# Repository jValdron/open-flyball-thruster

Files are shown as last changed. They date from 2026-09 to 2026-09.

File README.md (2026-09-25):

# open-flyball-thruster (OFT)

## Contents
- [Introduction](#introduction)
- [Flyball?](#flyball)
- [Word of Warning](#word-of-warning)
- [Instructions](#instructions)
  - [Assembly Timelapse](#assembly-timelapse)
- [Design](#design)
- [Contributions](#contributions)
- [License](#license)

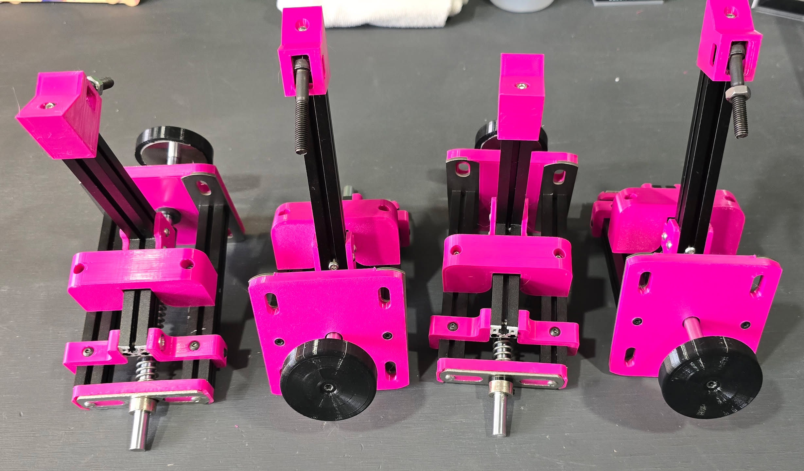
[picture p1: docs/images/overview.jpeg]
Overview of 4 thrusters


## Introduction
An **open-source**, **low-cost** [flyball](https://en.wikipedia.org/wiki/Flyball) thruster design aimed at DIY builders. This repository covers the **thrusters only**; it does not include any instructions for building a flyball box.

Thrusters are built from a mix of **printed parts** and **off-the-shelf hardware**, with some basic machining required. Printed parts are defined in [OpenSCAD](https://openscad.org/), with some customization available.

The target cost is, currently, approximately **$35 USD** per thruster, excluding tools and printer access.

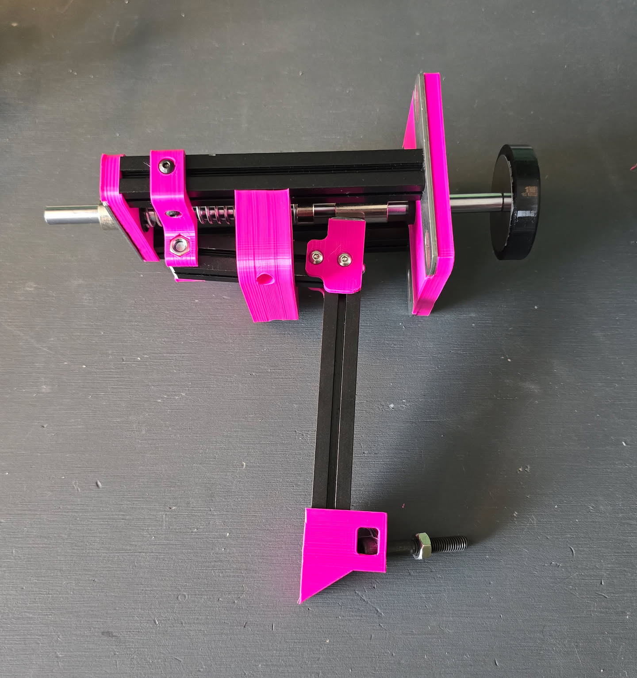
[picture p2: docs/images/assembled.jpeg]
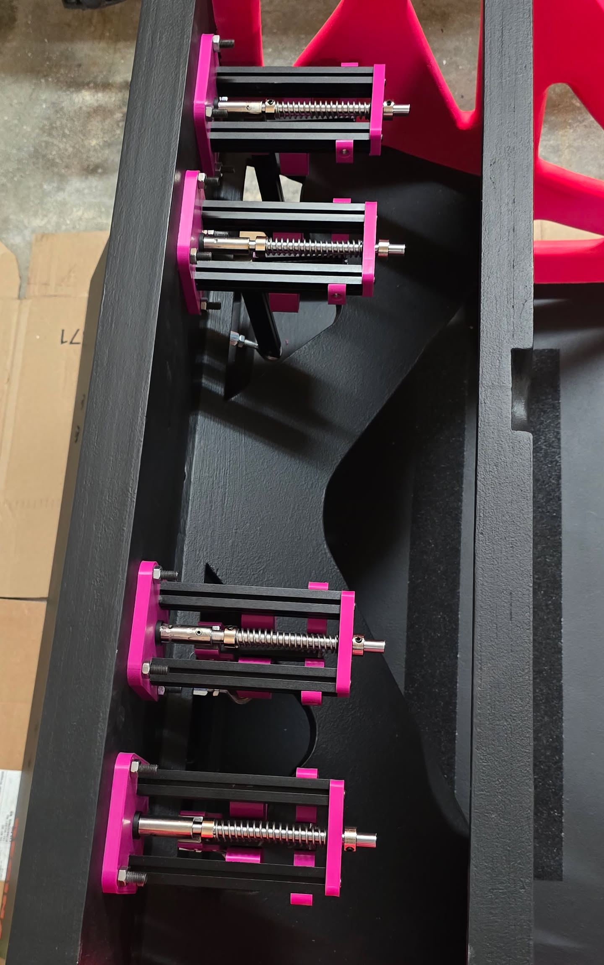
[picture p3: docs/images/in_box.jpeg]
Mounted in a box
|  |  |
|:---:|:---:|
| Side view | 4 thrusters mounted in a box (first version, no baffles/pedal connector) |

## Flyball?
If you don't know flyball, you probably don't need a flyball box thruster. Flyball is a fast paced team dog sport. It's somewhat of a relay race where four dogs race over jumps, trigger a box to retrieve a ball (shot out by a thruster) and race back while then next dog goes.

Common organizations are [NAFA](https://www.nafaflyball.com/) and [U-FLI](https://u-fli.com/) in North America, [BFA](https://www.flyball.org.uk/) and [UKFL](https://www.ukflyball.org.uk/) in the UK, and there are more in other parts of the world.

## Word of Warning
If you're here, you're most likely looking at building your own thruster. My first word of warning is that you probably shouldn't. You're better off buying thrusters from established suppliers, for example:
  - **[Jarvis Flyball Box](https://www.flyballbox.ca/)** (Canada)
  - **[Sub 15](https://www.facebook.com/p/Sub-15-61551941167602/)** (UK)
  
<sub>Please let me know if you would like your name added to or removed from the list above.</sub>

The OFTs:
- **are not battle-tested.** As of this writing, they haven't been used for more than a year. We've used them weekly at practice and a half dozen of times at various tournaments. They've been working without much issues for us and the last iteration has been pretty solid.

- **has many small parts.** Since these combine 3D printed parts and metal parts instead of custom machined parts, they contain many more small parts than a machined thruster would, making them more susceptible to breaking.

- **has 3D printed parts.** Some tension/stress will happen on printed parts, so you should fully expect some parts to break at some point. However, this was engineered in a way where most of the tension and stress will be distributed on metal fasteners and baffles. The important bits are mostly all metal. The printed parts are mostly there to support fasteners or metal parts.

- **should have spare parts.** I would definitely recommend you keep spare parts on hand, and ideally a complete spare thruster, so you can quickly replace failed components.

- **has no support or warranty.** All of the files and instructions provided in this repository are provided as is and with no support or warranty. I am not responsible for any accident, injuries or whatever happens while building or using these.

- **was built with AI-assisted SCAD.** The original design was completely done in Fusion 360, but at some point I stopped using Fusion and switched to OpenSCAD. [Cursor](https://cursor.com/) was used to help re-write the parts in OpenSCAD; they may contain errors, need iteration or might be sub-optimal.

## Instructions
This project is for **DIY-ers only**. You should have:

- **Basic metal-cutting tools** (e.g. saw, drill, tap and dies, etc) to machine some of the metal parts.
- **Access to a 3D printer** (your own or a maker space) for printing the OpenSCAD-generated parts.

Familiarity with OpenSCAD is helpful if you want to tweak dimensions or part geometry.

Acquire [parts (bom.md)](docs/bom.md) and follow [instructions.md](docs/instructions.md) to get started.

TL;DR:
* Obtain the all parts, see [docs/bom.md](docs/bom.md)
* Get the parts prepared, see [docs/instructions.md](docs/instructions.md)
* Assemble the thruster, see [docs/assembly.md](docs/assembly.md)
* Tune as necessary, see [docs/tuning.md](docs/tuning.md)

### Assembly Timelapse
https://github.com/user-attachments/assets/54a8cb0c-5971-4721-8ede-dae078966e4b

## Design

This is a fairly standard flyball thruster. A **main spring** on a **linear rod** drives the ball; a **shaft coupler** gives the rod two positions (rest and loaded). A **hammer/striker** holds the rod in the secondary (loaded) position via a small spring.

**To load:** Push back on the **plunger**. The thruster stays in the loaded position. The hammer head bears against the rod and keeps it in the secondary position.

**To fire:** Something must push back or down on the hammer to release the rod, typically a **bolt** between the box’s pedal and the hammer. The optional **pedal connector** is a printed part that sits between the pedal and the hammer to carry that screw.

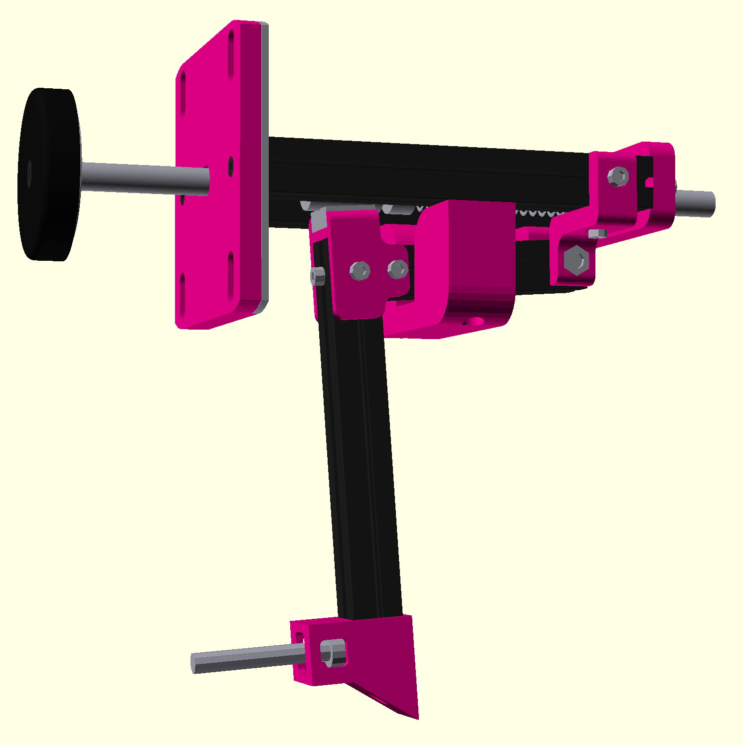
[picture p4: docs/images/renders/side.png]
Side view
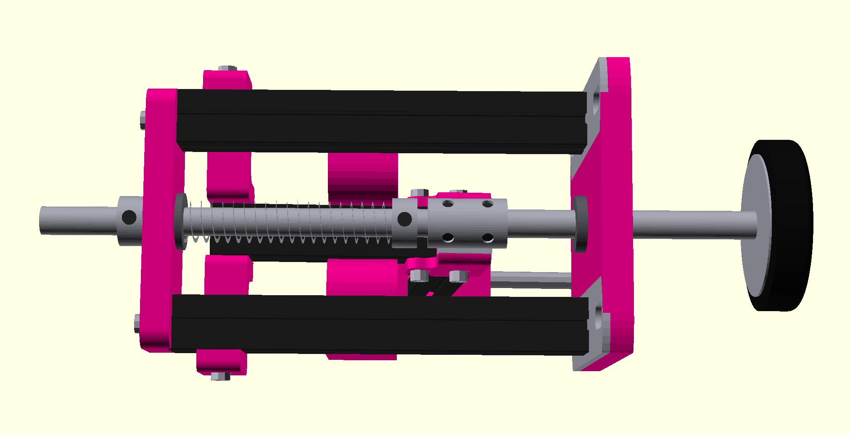
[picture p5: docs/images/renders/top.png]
Top view
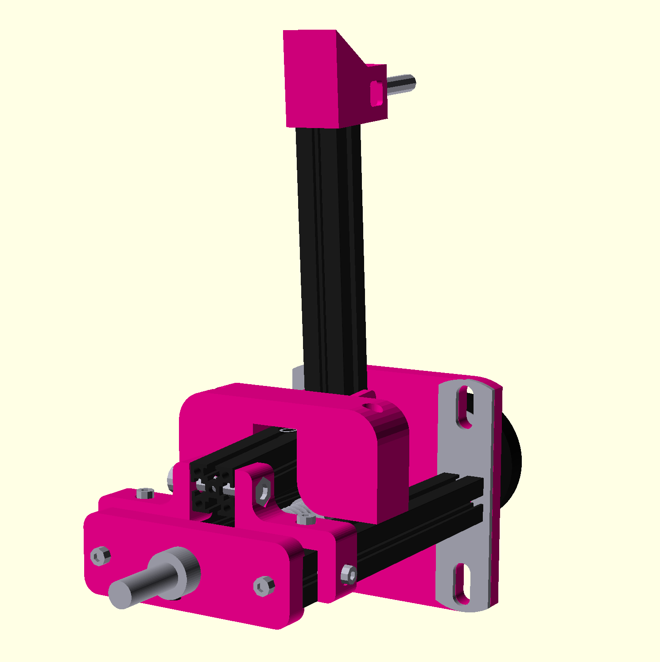
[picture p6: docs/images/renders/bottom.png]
Bottom view
|  |  |  |
|:---:|:---:|:---:|
| Side view | Top view | Bottom view |

## Contributions
Feel free to submit a pull request or start a discussion if you want to discuss something, but again, I do not provide support for these.

## License
All files are licensed as CC BY-NC-SA 4.0.

See [LICENSE](LICENSE) for the full legal text.

These designs are free to use, modify, and manufacture for personal and non-commercial club use. Commercial manufacture, sale, or commercial distribution is not permitted without permission from the author.

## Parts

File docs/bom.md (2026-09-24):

# Bill of Materials (BOM)

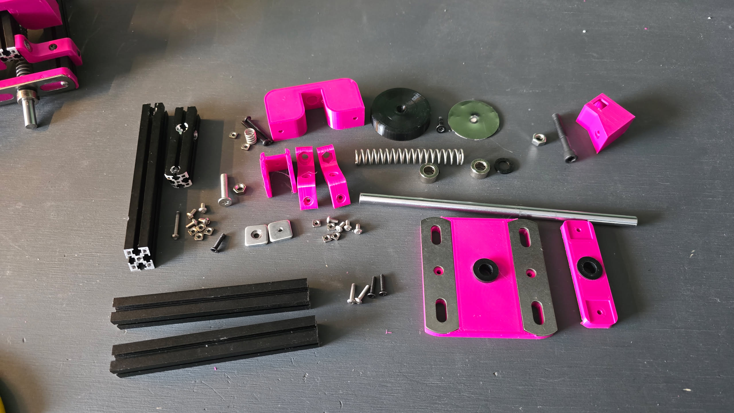
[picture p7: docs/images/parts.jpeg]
All parts (not 100% accurate)


## Intended configuration

This list is sized for a thruster mounted on a faceplate made of a double stack of 3/4" plywood (1½" total) with thinner matting (~¼") on top. As built, the thruster is quite adjustable, so small differences in board or matting thickness can usually be taken up without changing parts.

If the box is much different from that stack, you will likely need to tweak a few dimensions. The ones that matter most are the linear rod, the main spring, and potentially the extrusion lengths.

## BOM

Per-thruster parts list. Multiply quantities by the number of thrusters you want to build.

Prices are approximate (CAD from original sources); expect ~\$45–50 CAD, or ~\$35 USD, per thruster depending on source and shipping.

Some parts are best bought in bulk, such as the aluminum extrusion and any fasteners.

| Qty | Item | Cost/unit | Total | Notes / link |
|-----|---|---|---|---|
| | [Printed Parts – PETG](https://www.overture3d.ca/products/basic-petg-1-75mm-1-pack) | ~$2.49 | ~$2.49 | Print from STLs in `models/` |
| | [Printed Parts – TPU](https://www.overture3d.ca/products/tpu-1-75mm-1-pack) | ~$0.65 | ~$0.65 | |
| 2 | [1515 aluminum profiles × 115 mm](https://www.amazon.ca/dp/B06XJ42W51) (profile) | $3.34 [^1] | $6.68 | 15×15 mm extrusion for main profile |
| 1 | 1515 aluminum profiles × 65 mm (hammer) | $1.87 [^1] | $1.87 | Hammer top extrusion  |
| 1 | 1515 aluminum profiles × 135 mm (hammer) | $3.88 [^1] | $3.88 | Hammer side extrusion |
| 2 | [80×20×2 mm 304 stainless steel baffle](https://www.aliexpress.com/item/1005010628242895.html) | $3.92 | $7.84 | For the base. Optional, could be done without, but highly recommended due to strength it provides. Substitute listing — these are not the baffles originally used; that item is no longer listed |
| 1 | [70×20×2 mm 304 stainless steel baffle](https://www.aliexpress.com/item/1005010628242895.html) | $4.00 | $4.00 | For the backstop. Optional, also could be done without, but highly recommended due to strength |
| 1 | [M4x15x15x3mm square nut](https://www.aliexpress.com/item/1005008724571592.html?spm=a2g0o.order_list.order_list_main.181.52d11802MeMOAG) | $0.25 | $0.25 | Technically optional, can be printed instead but highly recommended that you machine it |
| 1 | [8 mm OD × 200 mm linear shaft with M4 threaded holes](https://www.aliexpress.com/item/1005007982728863.html) | $9.54 | $9.54 | ~7" |
| 1 | [12 mm OD × 1.2 mm wire × 70 mm compression spring](https://www.aliexpress.com/item/1005005402569008.html) | $0.93 | $0.93 | Main spring |
| 1 | [8 mm OD × 0.9 mm wire × 10 mm compression spring](https://www.aliexpress.com/item/1005005402584700.html) | $0.33 | $0.33 | Hammer spring |
| 2 | [8 mm shaft lock collar (T8)](https://www.aliexpress.com/item/32830905214.html) | $0.52 | $1.05 | |
| 1 | [40×40 mm metal plate disk](https://www.aliexpress.com/item/1005008983416584.html) | $0.56 | $0.56 | |
| 1 | [8–8 mm shaft coupler](https://www.aliexpress.com/item/1005010151471423.html) | $1.64 | $1.64 | |
| 4 | [M4 × 3 mm grub screws](https://www.aliexpress.com/item/1005007184737120.html) | $0.14 | $0.55 | |
| 2 | [M8 T-shaped nylon washer/bushing](https://www.aliexpress.com/item/1005008152448252.html) | $0.20 | $0.40 | |
| 1 | [M4 × 14 mm countersunk Torx machine screws](https://www.aliexpress.com/item/4001255830388.html) | $0.12 | $0.12 | |
| 3 | [M3 × 14 mm countersunk Torx machine screws](https://www.aliexpress.com/item/4001255830388.html) | $0.08 | $0.24 | |
| 8 | [M3 × 6 mm button head machine screws](https://www.aliexpress.com/item/32967225441.html) | $0.05 | $0.43 | |
| 2 | [M3 × 10 mm button head machine screws](https://www.aliexpress.com/item/32967225441.html) | $0.06 | $0.13 | |
| 2 | [M3 × 12 mm button head machine screws](https://www.aliexpress.com/item/32967225441.html) | $0.07 | $0.13 | |
| 1 | [M3 × 25 mm socket head cap machine screws](https://www.aliexpress.com/item/32980100109.html) | $0.10 | $0.10 | |
| 2 | [M3 × 30 mm button head machine screws](https://www.aliexpress.com/item/32967225441.html) | $0.10 | $0.20 | |
| 10 | [M3 square nuts](https://www.aliexpress.com/item/1005009866787243.html) | $0.05 | $0.50 | To fasten parts on the 15x15 extrusion |
| 1 | [M5 × 25 mm flat Torx machine screws](https://www.aliexpress.com/item/1005002254557923.html) | $0.87 | $0.87 | Hammer/catcher pivot |
| 1 | [M5 nuts](https://www.aliexpress.com/item/1005007593861199.html) | $0.12 | $0.12 | Hammer/catcher pivot |
| 4 | [M6 × 60 mm machine screws](https://www.aliexpress.com/item/1005008846077891.html) | $0.59 | $2.38 | Used to mount to the box, longer/shorter screws might be needed depending on faceplate thickness |
| 4 | [M6 nuts](https://www.aliexpress.com/item/1005007593861199.html) | $0.15 | $0.60 | Used to mount to the box |
| 1 | [M6 × 10 mm × 40 mm hex rod coupling nuts](https://www.aliexpress.com/item/1005006565508071.html) | $1.02 | $1.02 | Optional, pedal connector |
| 1 | [M6 × 40 mm partially threaded machine screws](https://www.aliexpress.com/item/32860422627.html) | $0.81 | $0.81 | Optional, pedal connector |
| 1 | [M6 × 20 mm flat head machine screws](https://www.aliexpress.com/item/1005008614137094.html) | $0.56 | $0.56 | Optional, pedal connector |
| | | | **~\$48.48** | Main list total (CAD) |
| | | | **+\$2.39** | With optional pedal connector (CAD) |

[^1]: **Aluminum extrusion unit cost:** Extrusion is bought in bulk (e.g. a pack of 4 × 1000 mm). The cost/unit shown is the **price per mm** (total pack price ÷ 4000 mm) × the length of that profile.

##  Notes

- **Printed parts:** Print all STLs in `models/` from the PETG and TPU allocations above (see [instructions.md](instructions.md) for print settings).
- **1515 profiles:** Often sold in multi-packs; one pack may cover several thrusters.
- **Sourcing:** Links are from the original BOM (Overture, Amazon.ca, AliExpress). You can substitute equivalent parts from local or preferred suppliers; confirm dimensions and thread specs (M3/M4/M5/M6) match.
- **Currency:** Original prices in CAD. USD equivalent is roughly 25–30% less depending on exchange rate.

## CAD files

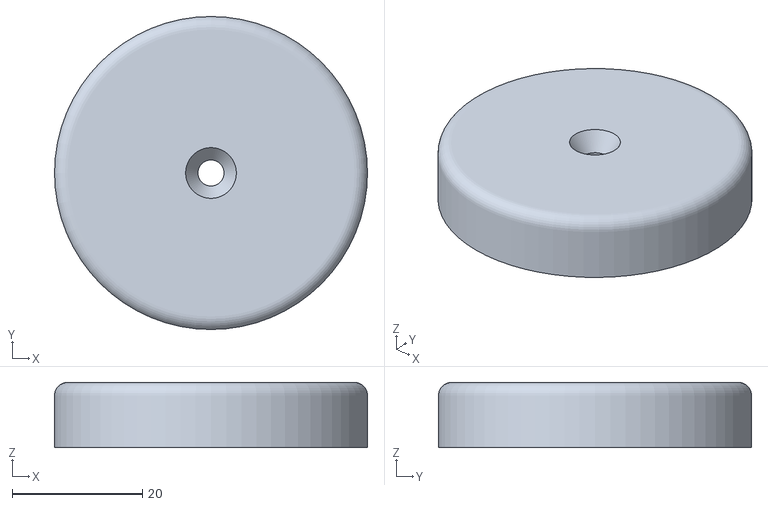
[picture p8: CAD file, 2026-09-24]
models/plunger.stl
48.0 x 48.0 x 10.0

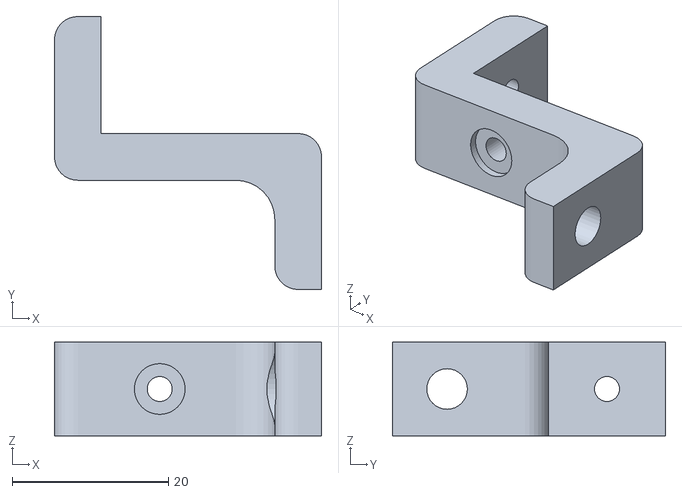
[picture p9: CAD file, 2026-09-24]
models/hammer_holder.stl
34.2 x 35.0 x 12.0

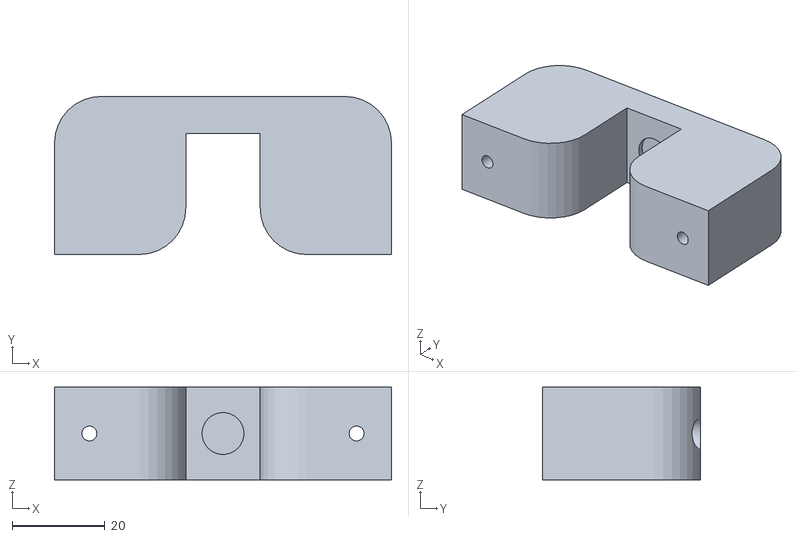
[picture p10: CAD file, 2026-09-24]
models/spring_holder.stl
72.5 x 34.0 x 20.0

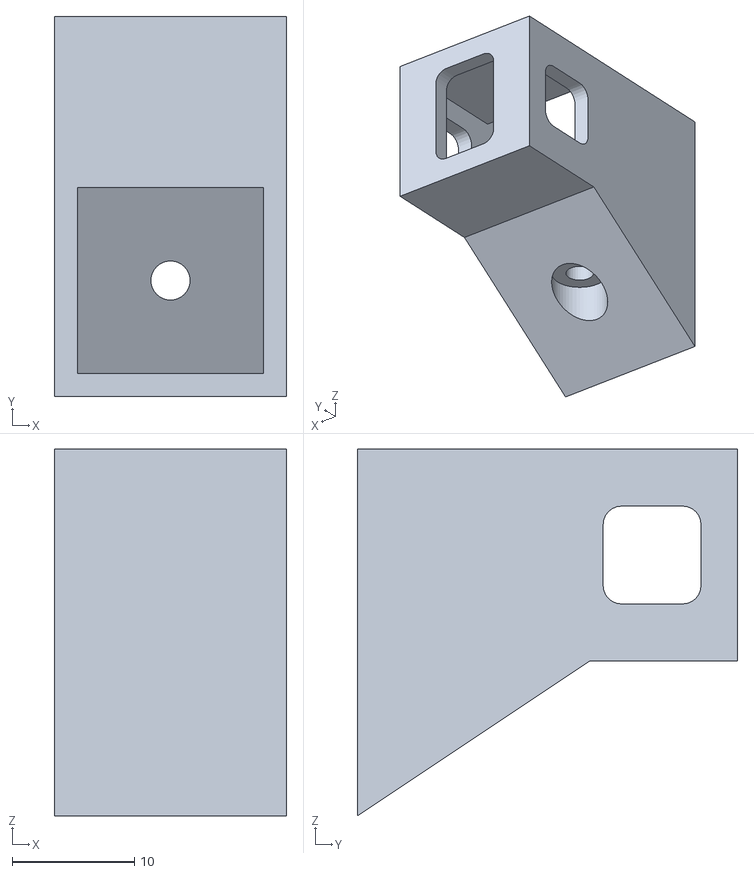
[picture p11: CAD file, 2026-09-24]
models/pedal_connector.stl
19.0 x 31.1 x 30.0

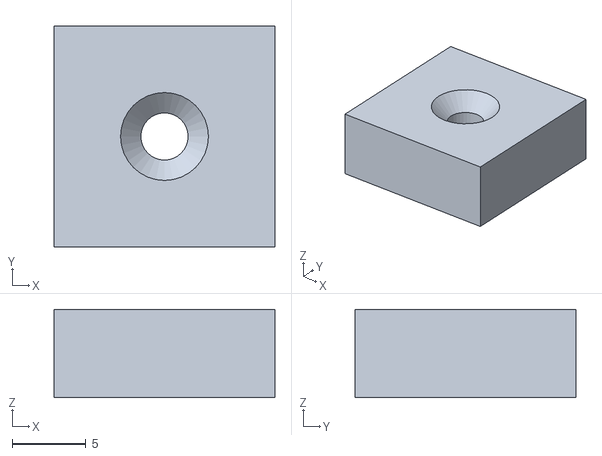
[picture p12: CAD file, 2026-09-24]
models/hammer_head.stl
15.0 x 15.0 x 6.00

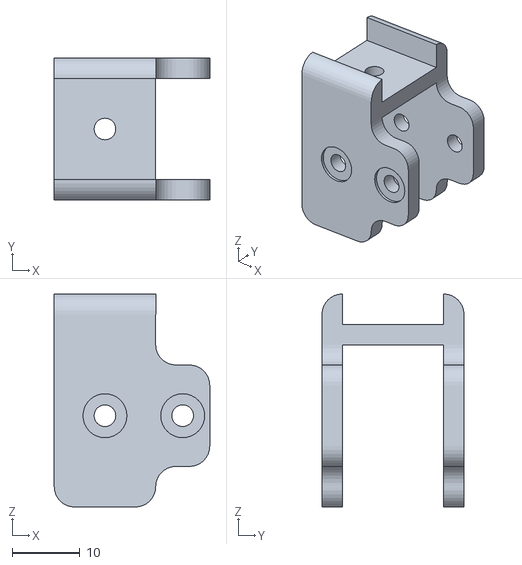
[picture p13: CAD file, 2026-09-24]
models/hammer_joint.stl
23.0 x 21.0 x 31.5

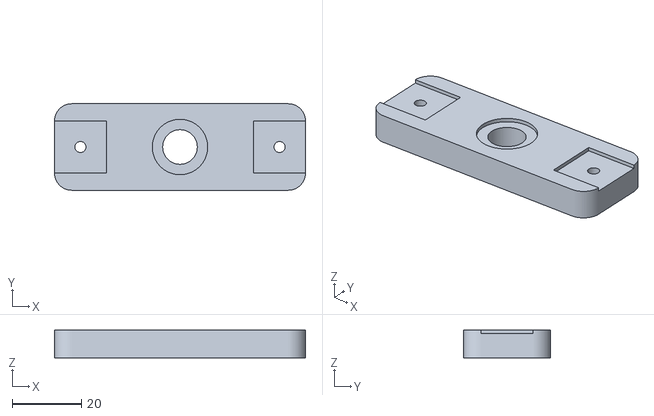
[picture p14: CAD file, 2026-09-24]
models/backstop.stl
72.5 x 25.0 x 8.00

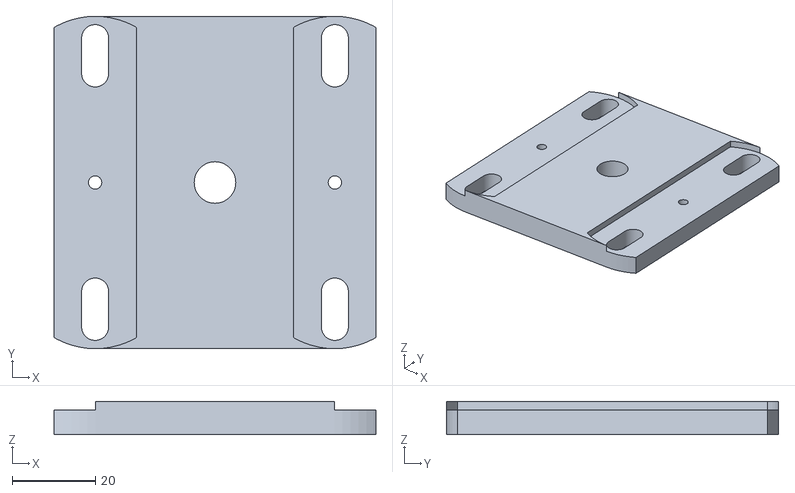
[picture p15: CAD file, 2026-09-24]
models/base.stl
77.5 x 80.0 x 8.00

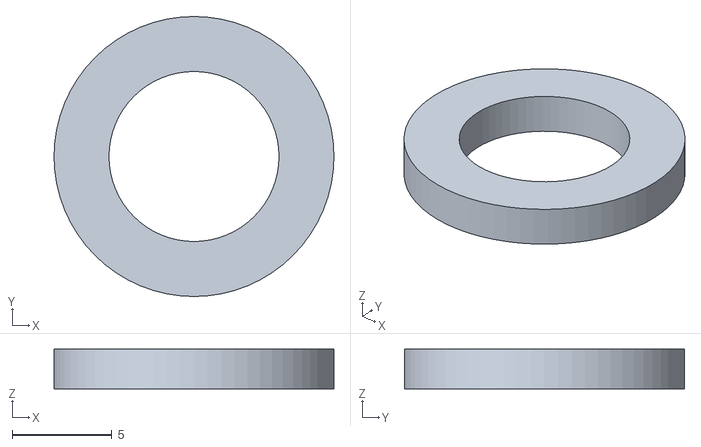
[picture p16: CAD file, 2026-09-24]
models/washer.stl
14.0 x 14.0 x 2.00

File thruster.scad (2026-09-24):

use <scad/lib/makerbeam.scad>
use <scad/lib/baffle.scad>
use <scad/lib/collars.scad>
use <scad/lib/t_bushing.scad>
use <scad/lib/compression_spring.scad>

use <BOLTS.scad>

use <scad/base.scad>
use <scad/backstop.scad>
use <scad/plunger.scad>
use <scad/hammer_holder.scad>
use <scad/hammer_joint.scad>
use <scad/hammer_head.scad>
use <scad/spring_holder.scad>
use <scad/pedal_connector.scad>

petg_color = [0.929, 0.0, 0.549];
extrusion_color = [0.12, 0.12, 0.12];
steel_color = [0.65, 0.65, 0.7];
anodized_steel_color = [0.15, 0.15, 0.15];
tpu_color = [0.05, 0.05, 0.05];
nylon_color = [0.35, 0.35, 0.38];

plate_size = [77.5, 80];
baffle_width = 19.9;
baffle_x_offset = plate_size[0]/2 - baffle_width/2;
plate_thickness = 8;
baffle_thickness = 2;

extrusion_length = 115;
hammer_top_extrusion_length = 65;
extrusion_groove_depth = 1;
extrusion_size = 15;

extrusion_center_offset = plate_size[0] / 2 - baffle_width / 2;
distance_between_outside_faces_of_extrusions = 2 * extrusion_center_offset + extrusion_size;

main_spring_od = 12;
main_spring_wire_d = 1.2;
main_spring_length = 70;

hammer_spring_od = 8;
hammer_spring_wire_d = 0.9;
hammer_spring_length = 10;

hammer_holder_depth = 12;
hammer_holder_backstop_offset = 8;
hammer_holder_wall = 6;
hammer_holder_x_offset = extrusion_size / 2 + hammer_holder_wall;
hardware_holder_height = 14;
hammer_holder_total_height = extrusion_size + hammer_holder_wall + hardware_holder_height;
hammer_holder_clearance_below_center = 10;
hammer_holder_z_offset = hammer_holder_total_height / 2 + hammer_holder_clearance_below_center;
hammer_holder_m3_groove_depth = 1;
hammer_holder_inner_corner_radius = 5;
hammer_extrusion_play = 1;
hammer_holder_extra_width = extrusion_center_offset - extrusion_size - hammer_holder_wall - hammer_extrusion_play / 2;
hammer_top_extrusion_offset = 3;
hammer_top_extrusion_m5_through_hole_d = 6.5;
hammer_top_extrusion_spring_holder_hole_d = 9;
hammer_top_extrusion_spring_holder_hole_offset = 20;
hammer_side_extrusion_length = 135;
hammer_side_extrusion_short_length = 125;
pedal_connector_z_offset = 15;
pedal_connector_m6_bolt_length = 40;

spring_holder_y_offset = 52.5;
spring_holder_height = 31;
spring_holder_thickness = 20;
spring_holder_screw_length = 30;
spring_holder_screw_extra_for_nut = 7;
spring_holder_m3_groove_depth = max(0, -1 * (spring_holder_height - spring_holder_screw_length - spring_holder_screw_extra_for_nut));

hammer_joint_wall = 3;
hammer_joint_bottom_offset = 6;
hammer_joint_right_offset = 8;
hammer_head_height_offset = 4.5;
hammer_head_height = 6;

linear_shaft_length = 200;
linear_shaft_extension = 40;
m4_tap_depth = 15;

plunger_disc_thickness = 0.6;
plunger_disc_radius = 20;
plunger_thickness = 10;
m4_screw_length = 16;

// Base plate
color(petg_color) {
    rotate([-90, 0, 0]) {
        base();
    }
}

// T-bushing in base plate
t_bushing_flange_thickness = 3;
color(nylon_color) {
    translate([0, plate_thickness + t_bushing_flange_thickness, 0]) {
        rotate([90, 0, 0]) {
            t_bushing();
        }
    }
}

// Linear shaft
color(steel_color) {
    translate([0, -linear_shaft_extension, 0]) {
        rotate([-90, 0, 0]) {
            difference() {
                // Rod
                cylinder(h = linear_shaft_length, r = 4, $fn = 64);

                // Tapped M4 hole
                translate([0, 0, -0.5]) {
                    cylinder(h = m4_tap_depth + 1, r = 1.65, $fn = 64);
                }
            }

            // Plunger Disc
            difference() {
                cylinder(h = plunger_disc_thickness, r = plunger_disc_radius, $fn = 64);
                translate([0, 0, -0.5]) {
                    cylinder(h = 1.6, r = 2.5, $fn = 64);
                }
            }
        }
    }
}

// Plunger
color(tpu_color) {
    translate([0, -linear_shaft_extension, 0]) {
        rotate([-90, 0, 0]) {
            rotate([0, 180, 0]) {
                translate([0, 0, plunger_disc_thickness]) {
                    plunger();
                }
            }
        }
    }
}

// M4 countersunk hex socket screw
// Goes through plunger and disc into tapped hole
color(anodized_steel_color) {
    translate([0, -linear_shaft_extension, 0]) {
        rotate([-90, 0, 0]) {
            rotate([0, 180, 0]) {
                translate([0, 0, plunger_disc_thickness + plunger_thickness]) {
                    rotate([180, 0, 0]) {
                        MetricHexSocketCountersunkHeadScrew(key="M4", l=m4_screw_length);
                    }
                }
            }
        }
    }
}

// Backstop
backstop_thickness = 8;
linear_shaft_groove_depth = 2;
backstop_y = extrusion_length + plate_thickness * 2 - extrusion_groove_depth;
stop_collar_thickness = 7;
stop_collar_od = 14;
spring_stop_collar_y = 55;
shaft_coupling_y = 30;

color(petg_color) {
    rotate([90, 0, 0]) {
        translate([0, 0, -extrusion_length - plate_thickness*2 + extrusion_groove_depth]) {
                backstop();
        }
    }
}

// T-bushing in backstop groove
color(nylon_color) {
    t_bushing_flange_thickness = 3;
    t_bushing_body_height = 5;
    bushing_length = t_bushing_flange_thickness + t_bushing_body_height;
    translate([0, backstop_y - backstop_thickness - linear_shaft_groove_depth, 0]) {
        rotate([-90, 0, 0]) {
            t_bushing();
        }
    }
}

// Main compression spring
backstop_bushing_front_y = backstop_y - backstop_thickness - linear_shaft_groove_depth + bushing_length;
spring_collar_face_y = spring_stop_collar_y + stop_collar_thickness / 2;
spring_length = backstop_bushing_front_y - spring_collar_face_y;

color(steel_color) {
    translate([0, spring_collar_face_y, 0]) {
        rotate([-90, 0, 0]) {
            compression_spring(
                od = main_spring_od,
                wire_d = main_spring_wire_d,
                length = main_spring_length
            );
        }
    }
}

// Backstop stop collar
backstop_collar_y = backstop_y + backstop_thickness - stop_collar_thickness;

color(steel_color) {
    translate([0, backstop_collar_y, 0]) {
        rotate([-90, 0, 0]) {
            stop_collar();
        }
    }
}
color(anodized_steel_color) {
    translate([0, backstop_collar_y + stop_collar_thickness / 2, stop_collar_od / 2 + 0.5]) {
        rotate([180, 0, 0]) {
            m4_grub_screw();
        }
    }
}

// Spring stop collar
color(steel_color) {
    translate([0, spring_stop_collar_y, 0]) {
        rotate([-90, 0, 0]) {
            stop_collar();
        }
    }
}
color(anodized_steel_color) {
    translate([0, spring_stop_collar_y + stop_collar_thickness / 2, stop_collar_od / 2 + 0.5]) {
        rotate([180, 0, 0]) {
            m4_grub_screw();
        }
    }
}

// Shaft coupling on linear rod
shaft_coupling_od = 14;
shaft_coupling_length = 22;

color(steel_color) {
    translate([0, shaft_coupling_y, 0]) {
        rotate([-90, -45, 0]) {
            shaft_coupling();
        }
    }
}

// Grub screws in shaft coupling holes
color(anodized_steel_color) {
    translate([0, shaft_coupling_y, 0]) {
        rotate([-90, 135, 0]) {
            for (angle = [0, 90]) {
                rotate([0, 0, angle]) {
                    for (z_pos = [shaft_coupling_length / 4, 3 * shaft_coupling_length / 4]) {
                        translate([0, shaft_coupling_od / 2, z_pos]) {
                            translate([0, -1, 0]) {
                                rotate([90, 90, 0]) {
                                    m4_grub_screw(length = 3);
                                }
                            }
                        }
                    }
                }
            }
        }
    }
}

// M3 hex socket head cap screws
// Goes through backstop and into extrusion
color(steel_color) {
    backstop_z = -extrusion_length - plate_thickness*2 + extrusion_groove_depth;
    for (side = [-1, 1]) {
        translate([side * extrusion_center_offset, -backstop_z, 0]) {
            rotate([90, 0, 0]) {
                MetricHexSocketHeadCapScrew(key="M3", l=12);
            }
        }
    }
}

// Spring holder
color(petg_color) {
    translate([-extrusion_center_offset - extrusion_size / 2, plate_thickness + spring_holder_y_offset, -extrusion_size / 2]) {
        rotate([-90, 0, 0]) {
            spring_holder();
        }
    }
}
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

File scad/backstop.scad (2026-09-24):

backstop_height = 25;
backstop_thickness = 8;
corner_radius = 5;

plate_size = [77.5, 80];
baffle_width = 20;
extrusion_size = 15;

extrusion_center_offset = plate_size[0] / 2 - baffle_width / 2;
backstop_width = 2 * extrusion_center_offset + extrusion_size;

extrusion_groove_size = extrusion_size + 0.1;
extrusion_groove_depth = 1;

linear_shaft_hole_radius = 5;
linear_shaft_groove_radius = 8;
linear_shaft_groove_depth = 2;
m3_hole_radius = 3.2 / 2;

module backstop() {
    difference() {
        // Main body
        linear_extrude(height = backstop_thickness) {
            minkowski() {
                square([backstop_width - 2 * corner_radius, backstop_height - 2 * corner_radius], center = true);
                circle(r = corner_radius, $fn = 64);
            }
        }

        // Linear shaft hole (centre)
        translate([0, 0, -0.5]) {
            cylinder(h = backstop_thickness + 1, r = linear_shaft_hole_radius, $fn = 64);
        }

        // Two M3 screw holes at extrusion centres
        for (side = [-1, 1]) {
            translate([side * extrusion_center_offset, 0, -0.5]) {
                cylinder(h = backstop_thickness + 1, r = m3_hole_radius, $fn = 32);
            }
        }

        // Groves on the face that mates with the extrusions
        for (side = [-1, 1]) {
            translate([side * extrusion_center_offset, 0, backstop_thickness - extrusion_groove_depth]) {
                linear_extrude(height = extrusion_groove_depth + 0.5) {
                    square([extrusion_groove_size, extrusion_groove_size], center = true);
                }
            }
        }

        // Circular groove around shaft
        translate([0, 0, backstop_thickness - linear_shaft_groove_depth]) {
            cylinder(h = linear_shaft_groove_depth + 0.5, r = linear_shaft_groove_radius, $fn = 64);
        }
    }
}

backstop();

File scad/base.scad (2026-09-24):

use <lib/baffle.scad>

plate_size = [77.5, 80];
plate_thickness = 8;

baffle_length = 80;
baffle_width = 20;
baffle_thickness = 2;
baffle_slot_width = 6.5;
baffle_slot_length = 15;
baffle_edge_offset = 2;
baffle_partial_arc_radius = 20;

linear_shaft_hole_radius = 5;
baffle_center_hole_radius = 1.6;
m3_countersink_head_radius = 3;
m3_countersink_depth = 2;

module base() {
    difference() {
        // Base plate
        linear_extrude(height = plate_thickness) {
            union() {
                square([plate_size[0]-baffle_partial_arc_radius, plate_size[1]], center = true);

                for (side = [-1, 1]) {
                    translate([side * (plate_size[0]/2 - baffle_partial_arc_radius/2), 0, 0]) {
                        rotate([0, 0, 90]) {
                            baffle_shape(baffle_length, baffle_width, baffle_partial_arc_radius);
                        }
                    }
                }
            }
        }

        // Linear shaft hole
        translate([0, 0, -0.5]) {
            cylinder(h = plate_thickness + 1, r = linear_shaft_hole_radius, $fn = 64);
        }

        // Baffle recesses and holes - mirrored left and right
        baffle_recess_clearance = 0.1;
        baffle_x_offset = plate_size[0]/2 - baffle_width/2 + baffle_recess_clearance;

        for (side = [-1, 1]) {
            baffle_x = side * baffle_x_offset;

            // Baffle recess - with clearance
            translate([baffle_x, 0, plate_thickness - baffle_thickness - baffle_recess_clearance]) {
                linear_extrude(height = baffle_thickness + baffle_recess_clearance + 0.5) {
                    rotate([0, 0, 90]) {
                        baffle_shape();
                    }
                }
            }

            // Baffle holes
            translate([baffle_x, 0, 0]) {
                rotate([0, 0, 90]) {
                    baffle_holes(
                        center_hole_radius = baffle_center_hole_radius,
                        slot_width = baffle_slot_width,
                        slot_length = baffle_slot_length,
                        edge_offset = baffle_edge_offset,
                        length = baffle_length,
                        height = plate_thickness
                    );
                }
            }

            // Baffle center hole chamfer
            translate([baffle_x, 0, -0.5]) {
                cylinder(h = m3_countersink_depth + 1, r1 = m3_countersink_head_radius, r2 = baffle_center_hole_radius, $fn = 64);
            }
        }
    }
}

base();

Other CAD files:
models/hammer_holder_nut.stl
scad/hammer_head.scad
scad/hammer_holder.scad
scad/hammer_joint.scad
scad/pedal_connector.scad
scad/plunger.scad
scad/spring_holder.scad
scad/washer.scad

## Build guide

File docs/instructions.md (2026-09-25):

# Build Instructions

These instructions cover the **thrusters only**. They do not include any instructions for building a flyball box.

Follow these steps to get all parts ready for assembly. Then see [assembly.md](assembly.md) to put the thruster together.

- [Tools required](#tools-required)
- [1. Obtain parts from the BOM](#1-obtain-parts-from-the-bom)
- [2. Print the solid (PETG) parts](#2-print-the-solid-petg-parts)
- [3. Print the TPU parts](#3-print-the-tpu-parts)
- [4. Aluminum extrusions](#4-aluminum-extrusions)
  - [4.1 Profile extrusions](#41-profile-extrusions-2-pieces)
  - [4.2 Hammer top extrusion](#42-hammer-top-extrusion-1-piece)
  - [4.3 Hammer side extrusion](#43-hammer-side-extrusion-1-piece)
- [5. Hammer head](#5-hammer-head)
- [6. Plunger metal plate](#6-plunger-metal-plate)
- [7. Base and backstop bushings](#7-base-and-backstop-bushings)
  - [7.1 Ensure proper fit](#71-ensure-proper-fit-optional)
- [8. Backstop baffle](#8-backstop-baffle-optional-but-recommended)

| Blowout view of all parts |
|:--:|
| *Blowout view of all parts after this set of instructions and before assembly.* |

## Tools required

- M3 tap
- Drill (ideally a drill press for straight holes) and bits:
  - 3.2mm
  - 4mm
  - 5.5mm
  - 8mm
  - 9mm
- Something to cut aluminum extrusions
  - Mitre saw with a metal blade is a good solution
- Step drill bit (for enlarging the 70 mm baffle hole)
- Screw drivers for all the various screws
- Cutting oil
- Threadlocker

## 1. Obtain parts from the BOM

Gather all items from the [Bill of Materials (BOM.md)](BOM.md). Multiply quantities by the number of thrusters you are building. Order or source printed materials (PETG, TPU), aluminum profiles, hardware, and any optional items before starting.

## 2. Print the solid (PETG) parts

**Material:** PETG is highly recommended for the rigid printed parts.

- Slice the STLs with your favorite slicer.
- **Print orientation:** Recommended orientation for each part:
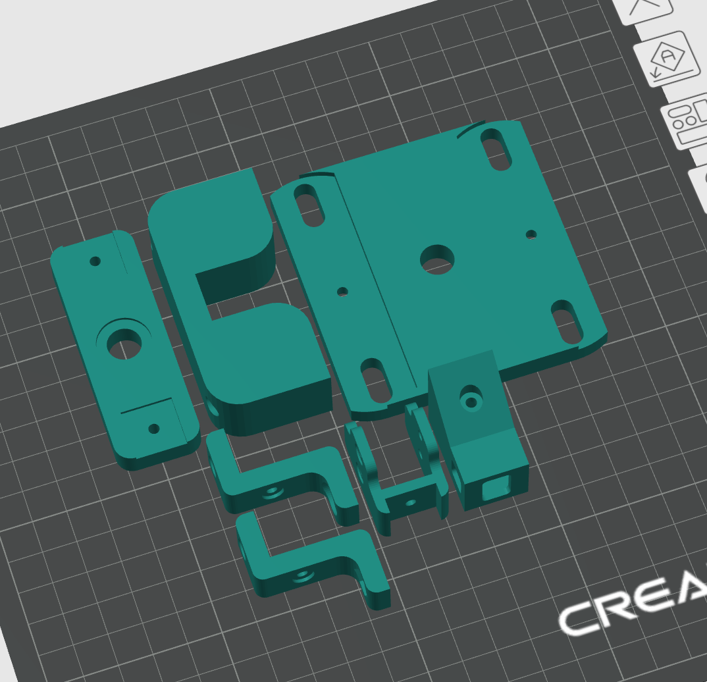
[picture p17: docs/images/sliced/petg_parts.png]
PETG parts print orientation
  
- **Supports:** Depending on your printer, no support should be required for any of the PETG parts.
- **Layer height:** 0.16 mm or 0.2 mm.
- **Infill:** Around 33%.
- **Walls:** For strong parts, use at least 5 walls (perimeters).

Print all rigid parts from the `parts/` folder that are intended for PETG:
- `backstop.stl`
- `base.stl`
- `hammer_head_nut.stl`
- `hammer_holder.stl`
- `spring_holder.stl`
- `pedal_connector.stl` (optional)
- `hammer_head.stl` (not recommended)

Optionally, you can print hammer head, but it's recommended that you use a metal part (see Step 5). PETG will wear out very quickly and it will require constant replacement.

## 3. Print the TPU parts

**Parts:** Plunger and, at least, one washer (or two).

- **Plunger:** Print with **100% infill** in TPU.
- **Washer:** The washer is thin and will likely slice with no infill. Ideally you could use two of these per thruster, they're used to dampen some of the vibration.
- **Skirt:** On my printer, I've had to set a minimum of 10 skirt layers to prevent a side of the plunger to lift from the bed.
- **Reference:** Orientation/layout:
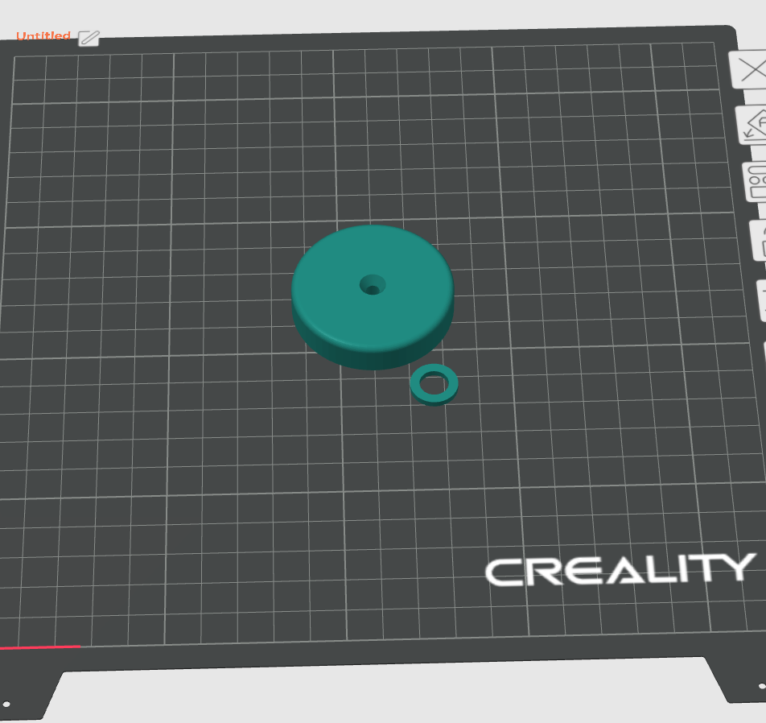
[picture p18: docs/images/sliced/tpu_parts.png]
TPU parts print orientation
  

## 4. Aluminum extrusions

A total of **4 pieces** are needed: **two for the main profile** and **two for the hammer** (one hammer top, one hammer side).

The two main profile pieces must be cut **accurately, straight, and the same exact length**. A cheap way to do this is a **mitre saw with a metal blade**, aluminum cuts easily. Measure the length you need with a caliper, then clamp a piece of wood as a stop so you can butt the extrusion against it and repeat the same cut.

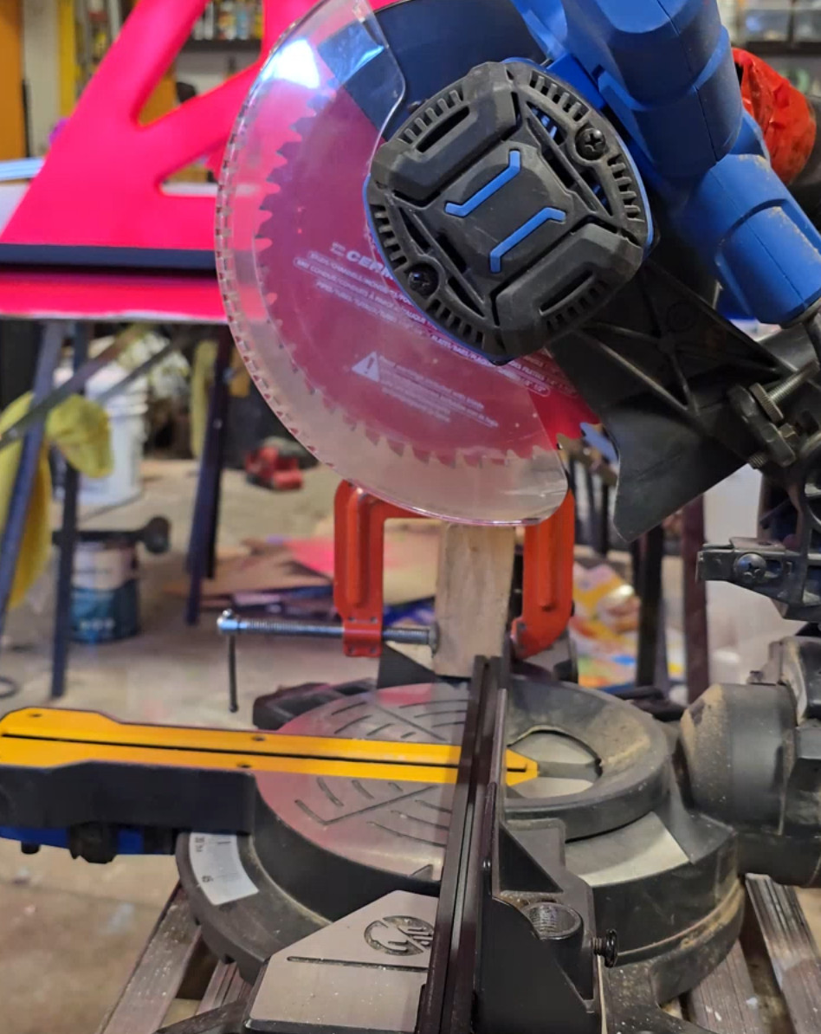
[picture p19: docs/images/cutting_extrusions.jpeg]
Cutting extrusion with mitre saw
|  |
|:--:|
| *Aluminum extrusion (black) on mitre saw with 2×4 clamped 115 mm from the blade.* |

### 4.1 Profile extrusions (2 pieces)

- Cut **straight** to **115 mm** length; both pieces must be identical.
- Tap **M3 threads at both ends** of each piece.

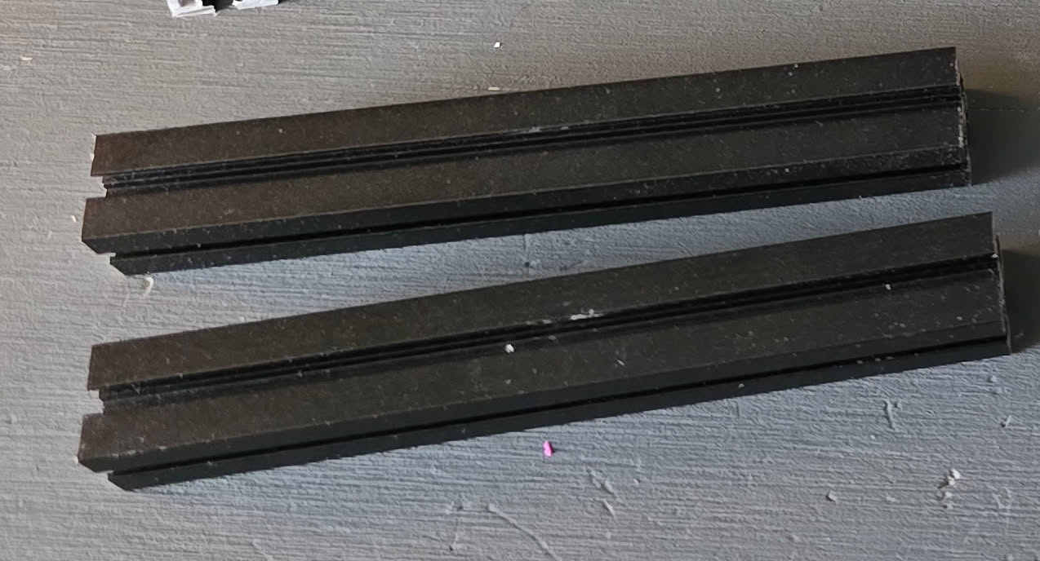
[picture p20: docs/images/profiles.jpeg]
Profile extrusions
|  |
|:--:|
| *Two 115 mm profile extrusions, cut to the same length.* |

### 4.2 Hammer top extrusion (1 piece)

This part swivels and springs back the hammer.

- Cut to **65 mm**.
- **One end**, the end that will blind-joint to the hammer side extrusion, tap **M3 threads** (opposite end of the 5.5mm through hole).
- **5.5 mm through hole** at ~5 mm from the other end. This is for the M5 bolt that goes through both hammer holders.
- **9 mm groove** bored ~20 mm from the front. This is where the hammer spring sits.

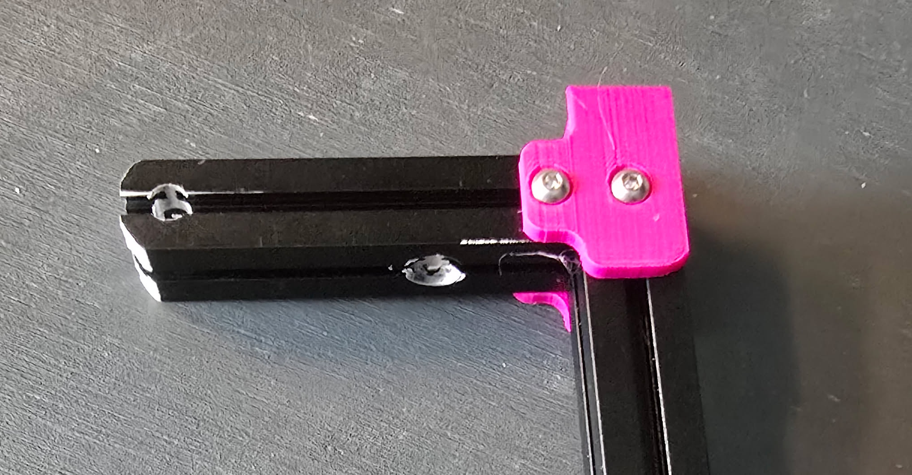
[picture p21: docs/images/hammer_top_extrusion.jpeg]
Hammer top extrusion
|  |
|:--:|
| *Hammer top extrusion, 65 mm long with 9 mm groove for the spring and 5.5 mm through hole.* |

### 4.3 Hammer side extrusion (1 piece)

- **Without pedal connector:** Cut **135 mm** long.
- **With pedal connector:** Cut at an angle so the **shorter side is 125 mm** and the **longer side is 135 mm**. Set the mitre blade to approximately **32.5°**.
- **3.2 mm through hole** at **11 mm from the top**.
- **Top hole:** tap **M3 threads**.
- **If using the pedal connector:** also tap the **bottom hole** with **M3 threads**.

## 5. Hammer head

The hammer head is *technically optional*, it *could* be printed (e.g. from PETG), but **machining it from steel is highly recommended**. A PETG hammer head will wear out quickly and require constant replacement.

Using the **M4 × 15 × 15 × 3 mm square nut** from the BOM, use a **larger drill bit to taper (countersink) the hole on one side** so the countersunk screw sits flush and does not stick out of the hammer head.

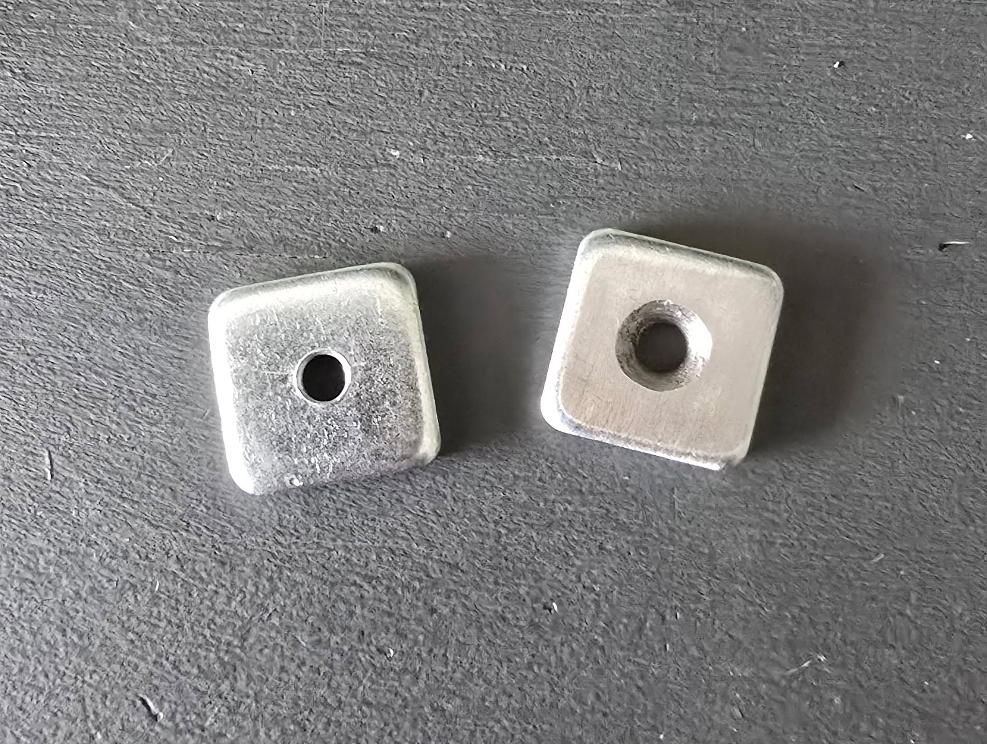
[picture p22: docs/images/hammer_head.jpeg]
Machined hammer head
|  |
|:--:|
| *Machined square nut: bottom (left) and countersunk top (right).* |

## 6. Plunger metal plate

Using the **40×40 mm metal plate disk** from the BOM, drill a **4 mm hole in the middle** of the plate.

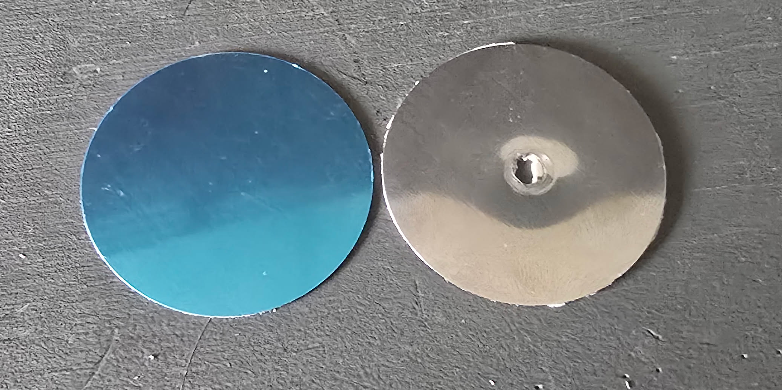
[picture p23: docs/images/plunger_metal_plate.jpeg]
Plunger metal plate
|  |
|:--:|
| *Stock plate (left) and drilled plunger plate (right).* |

## 7. Base and backstop bushings

Add a drop of super glue, then snap-push an **M8 T-shaped nylon washer/bushing** into the `base.stl` part so it does not pop out.

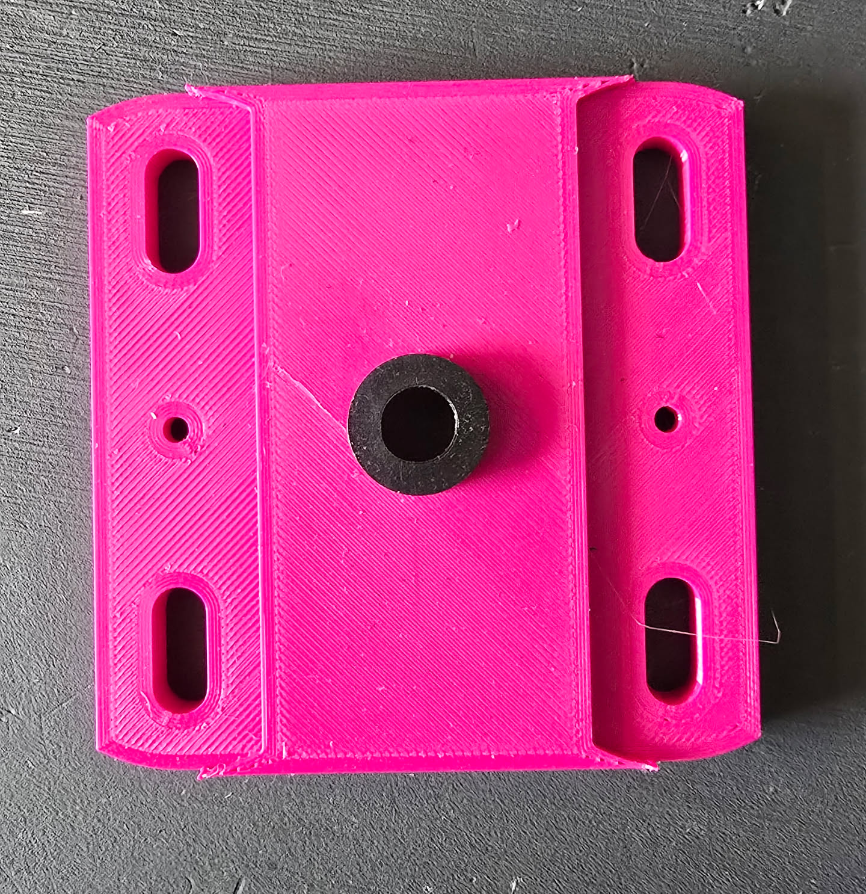
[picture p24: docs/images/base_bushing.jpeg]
Base bushing
|  |
|:--:|
| *M8 T-shaped nylon bushing snap-pushed into the base.* |

Do the same for `backstop.stl`.

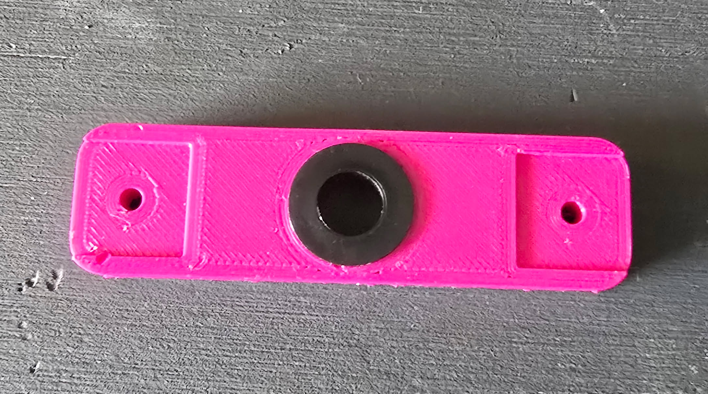
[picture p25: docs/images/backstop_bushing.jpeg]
Backstop bushing
|  |
|:--:|
| *M8 T-shaped nylon bushing snap-pushed into the backstop.* |

### 7.1 Ensure proper fit (optional)

Take a linear rod and check that it can slide nicely through both bushings. If there is resistance, drill the bushing back and forth with an **8 mm** bit until the linear rod can slide loosely.

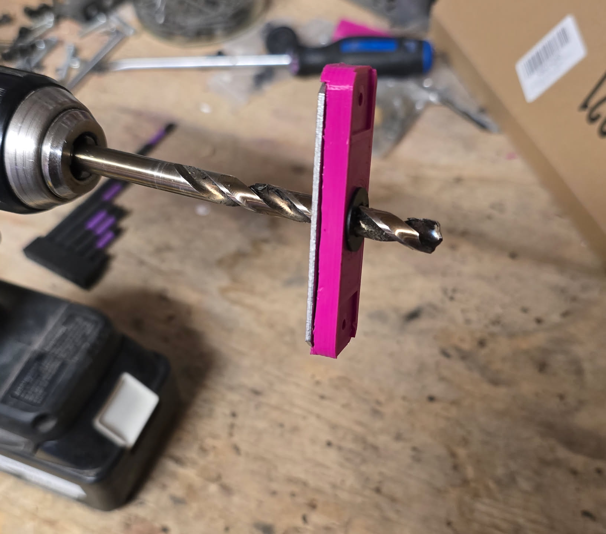
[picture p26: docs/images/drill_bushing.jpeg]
Drilling a bushing
|  |
|:--:|
| *Opening up a bushing with an 8 mm bit so the linear rod slides freely.* |

## 8. Backstop baffle (optional, but recommended)

Using the **70×20×2 mm 304 stainless steel baffle** from the BOM, enlarge the **hole in the middle**. A **step drill bit** makes this easy.

If you decide to omit this baffle, I would modify the backstop SCAD by removing the baffle and making it thicker.

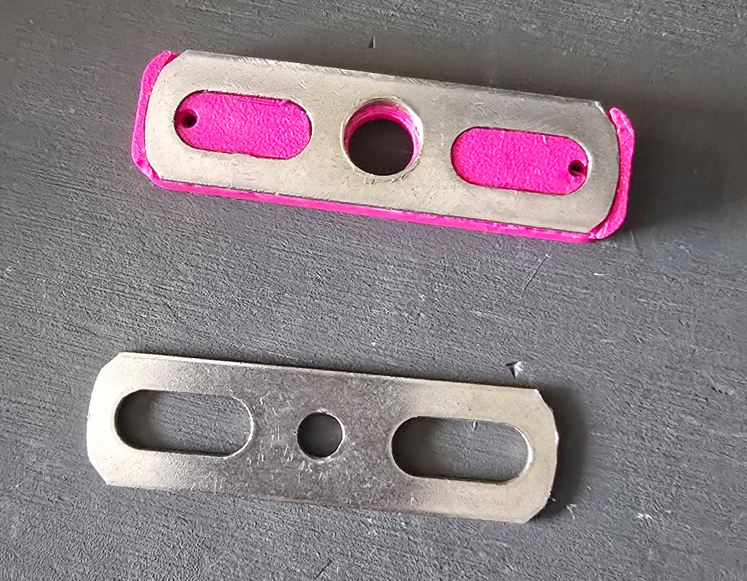
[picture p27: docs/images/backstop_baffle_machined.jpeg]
Machined backstop baffle
|  |
|:--:|
| *Enlarged center hole seated on the backstop (top) vs stock hole (bottom).* |

## Assembly

Once PETG and TPU parts are printed, extrusions, hammer head, plunger plate, bushings, and optional baffle are machined, and all BOM items are on hand, continue to [assembly.md](assembly.md).

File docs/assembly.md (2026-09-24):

# Assembly

Gather all items from the [Bill of Materials](bom.md) and prepare the printed parts, extrusions, hammer head, and plunger plate as described in [instructions.md](instructions.md). Then assemble in the order below.

- [1. Hammer](#1-hammer)
  - [1.1 Prepare the hammer joint](#11-prepare-the-hammer-joint)
  - [1.2 Fit the hammer side extrusion](#12-fit-the-hammer-side-extrusion)
  - [1.3 Fit the hammer top extrusion](#13-fit-the-hammer-top-extrusion)
  - [1.4 Blind-join the extrusions](#14-blind-join-the-extrusions)
  - [1.5 Attach the hammer head](#15-attach-the-hammer-head)
- [2. Plunger](#2-plunger)
- [3. Main body](#3-main-body)
  - [3.1 Baffles](#31-baffles)
  - [3.2 Extrusions](#32-extrusions)
  - [3.3 Nuts](#33-nuts)
  - [3.4 Backstop](#34-backstop)
- [4. Linear rod](#4-linear-rod)
- [5. Hammer assembly](#5-hammer-assembly)
  - [5.1 Hammer holders](#51-hammer-holders)
  - [5.2 Hammer spring](#52-hammer-spring)
- [6. Pedal connector](#6-pedal-connector-optional)
- [Mounting](#mounting)

## 1. Hammer

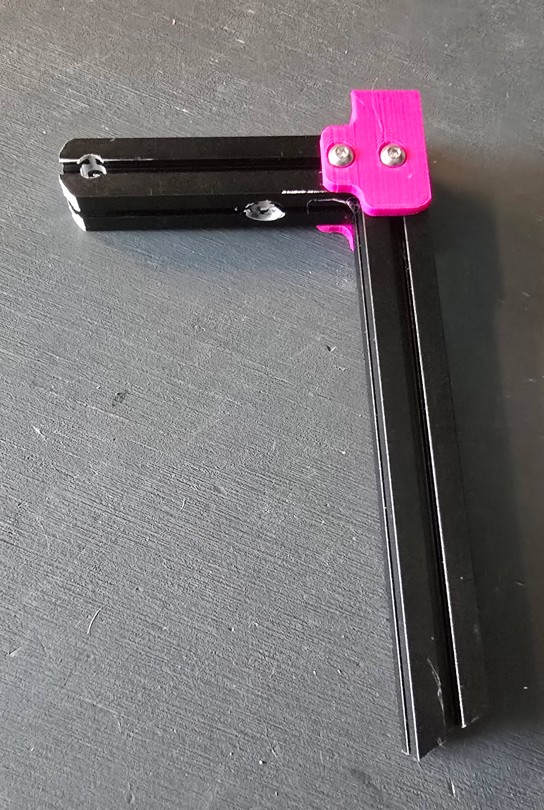
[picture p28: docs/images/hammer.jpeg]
Completed hammer
|  |
|:--:|
| *Completed hammer: side and top extrusions joined at the hammer joint.* |

You will need:

- Hammer joint (`hammer_joint.stl`)
- Hammer side extrusion
- Hammer top extrusion
- Machined hammer head (**M4 × 15 × 15 × 3 mm** square nut)
- **4 × M3 × 6 mm** button head screws
- **4 × M3** square nuts
- **1 × M4 × 14 mm** countersunk Torx screw
- **1 × M3 × 25 mm** socket head cap screw

### 1.1 Prepare the hammer joint

Put the **4 × M3 × 6 mm** button screws through the holes in the hammer joint and **loosely** thread an **M3 square nut** onto each one. Leave them loose enough that the nuts can slide into the extrusion T-slots.

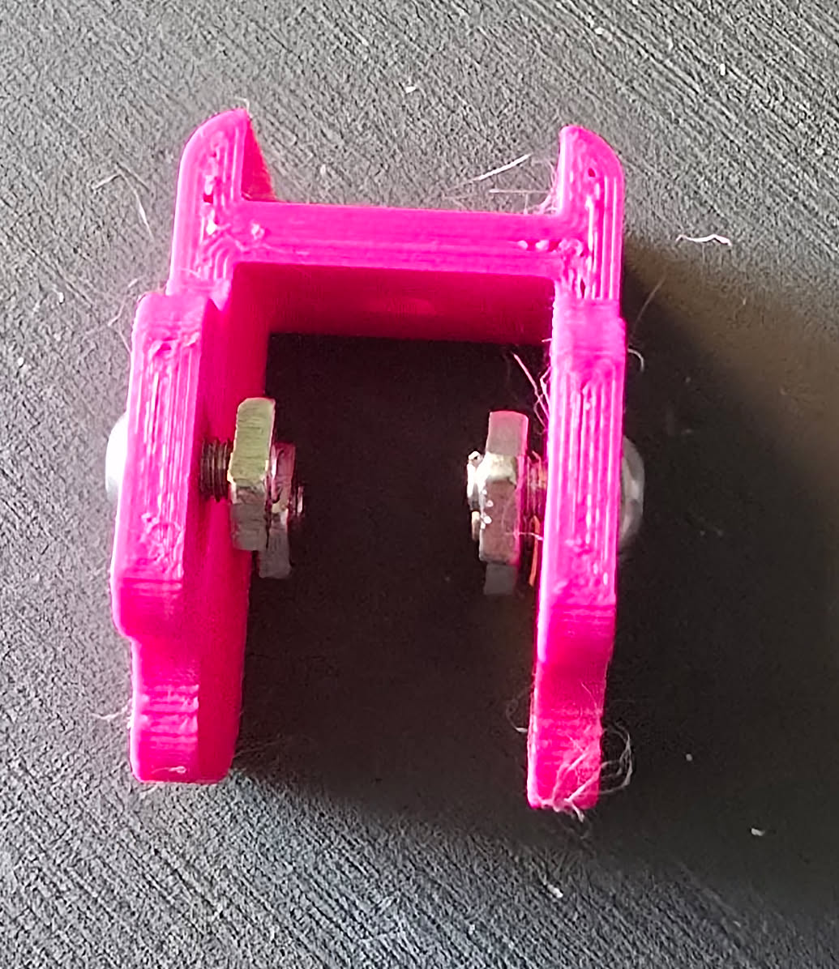
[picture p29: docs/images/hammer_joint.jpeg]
Hammer joint with screws and nuts
|  |
|:--:|
| *Hammer joint with M3 × 6 mm button screws and square nuts loosely threaded on.* |

### 1.2 Fit the hammer side extrusion

Slide the hammer joint onto the **top** of the hammer side extrusion (the end with the **3.2 mm** through hole). The square nuts should drop into the extrusion T-slots. Line the joint up so it sits at the top of the extrusion, then tighten the two screws.

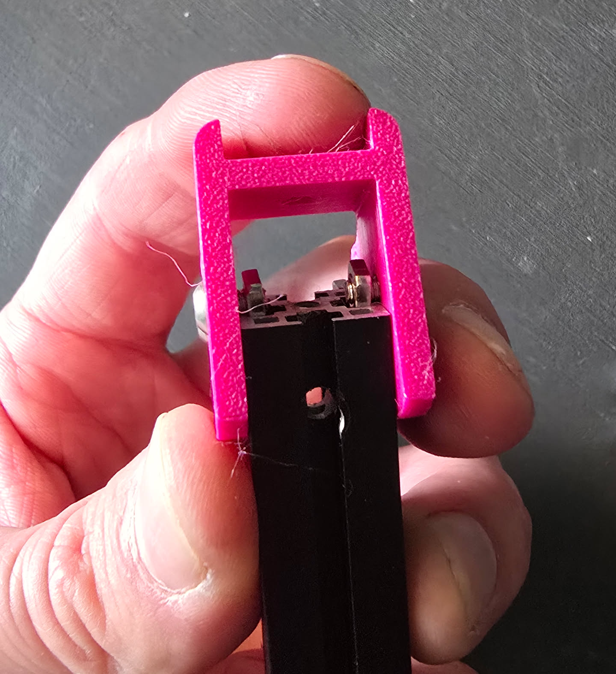
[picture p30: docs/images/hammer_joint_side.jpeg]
Hammer joint on side extrusion
|  |
|:--:|
| *Hammer joint slid onto the hammer side extrusion, nuts in the T-slots.* |

### 1.3 Fit the hammer top extrusion

Slide the hammer top extrusion into the remaining opening of the hammer joint, **tapped end first** (opposite the 5.5 mm through hole). Line it up with the side extrusion so the two pieces meet at a right angle, then tighten the remaining two screws.

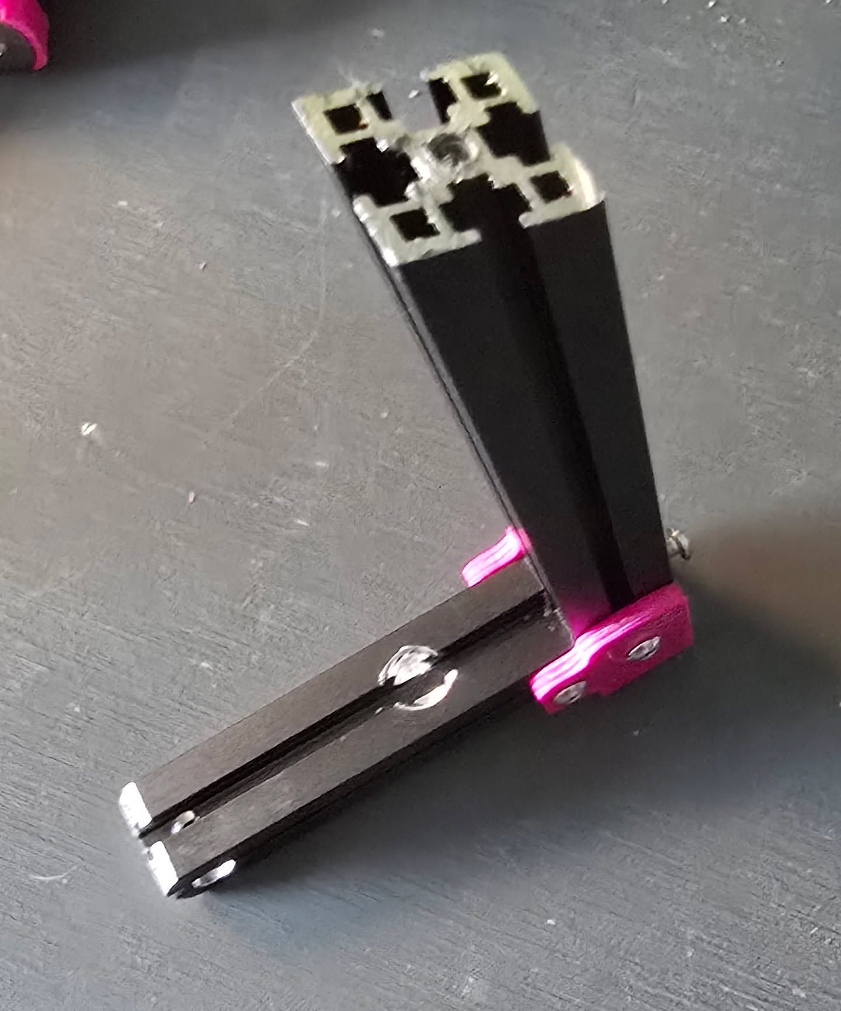
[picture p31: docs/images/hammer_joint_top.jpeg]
Hammer joint with both extrusions
|  |
|:--:|
| *Hammer top extrusion slid into the joint, forming an L with the side extrusion.* |

### 1.4 Blind-join the extrusions

Join the side extrusion to the top extrusion with the **M3 × 25 mm** socket head cap screw: pass it through the **3.2 mm** hole in the side extrusion and into the **tapped end** of the top extrusion. Tighten it so the two extrusions are pulled together inside the joint.

### 1.5 Attach the hammer head

Seat the machined **M4 × 15 × 15 × 3 mm** square nut in the recess on top of the hammer joint, over the side extrusion. Countersunk side facing out. Fasten it to the **top of the side extrusion** with the **M4 × 14 mm** countersunk Torx screw so the head sits flush.

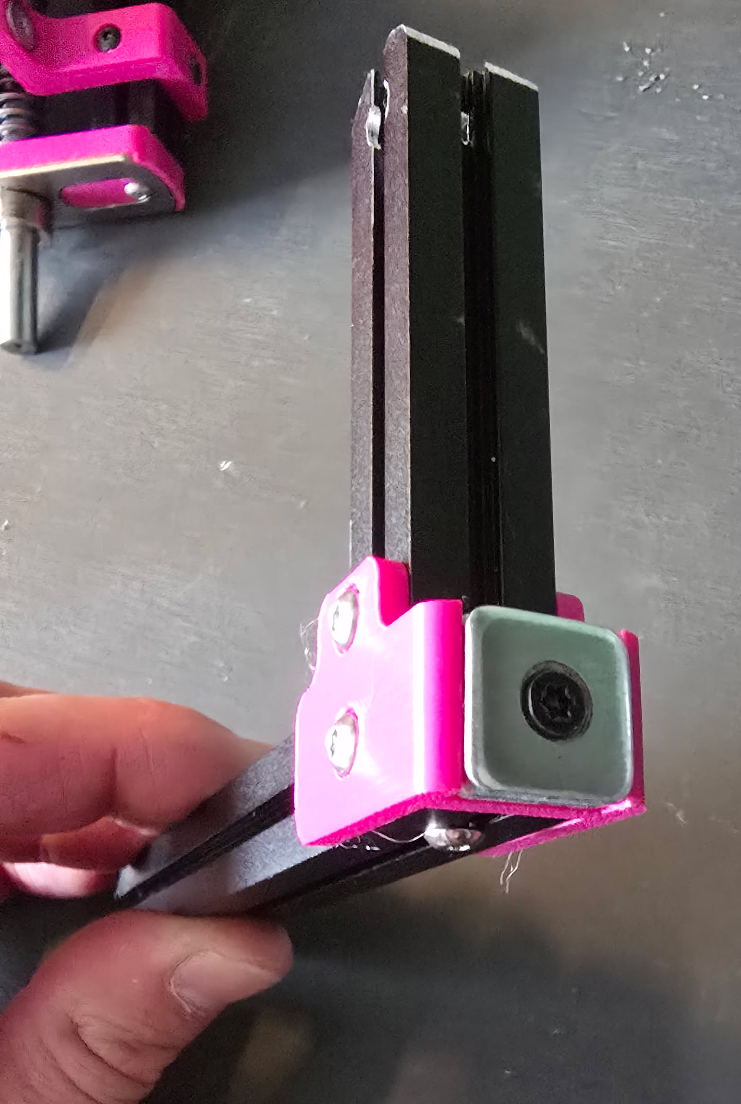
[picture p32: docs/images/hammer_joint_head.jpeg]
Hammer head attached
|  |
|:--:|
| *Hammer head (square nut) fastened to the top of the side extrusion with the M4 × 14 mm countersunk screw.* |

## 2. Plunger

You will need:

- Plunger (`plunger.stl`)
- Machined plunger metal plate
- Linear rod (**8 mm OD × 200 mm**, M4 threaded ends)
- **1 × M4 × 14 mm** countersunk Torx screw

Stick the plunger metal plate to the `plunger.stl` TPU part and pass the **M4 × 14 mm** countersunk Torx screw through the plunger.

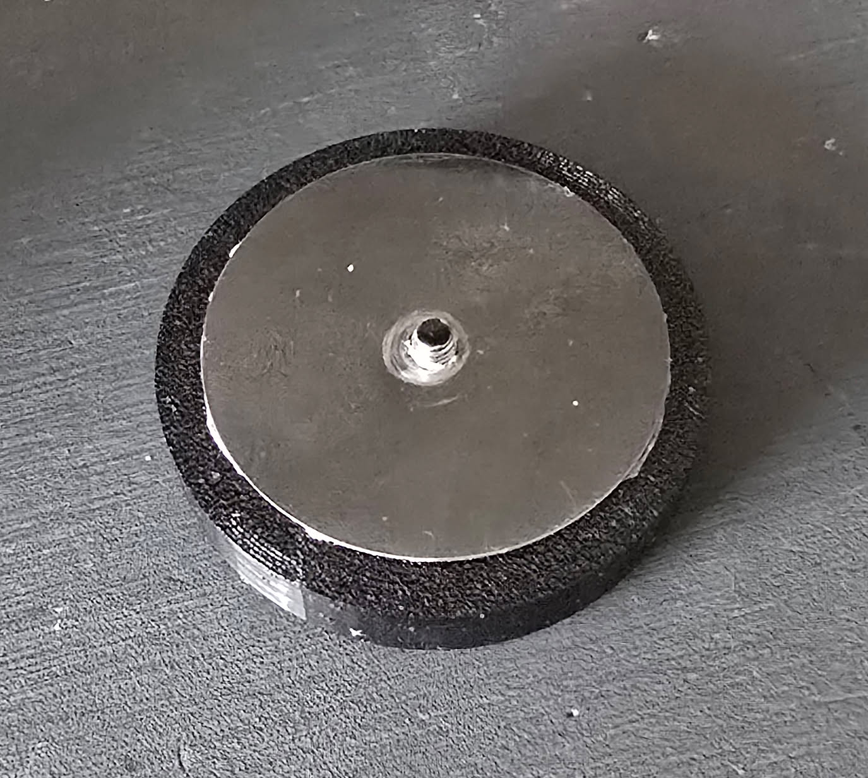
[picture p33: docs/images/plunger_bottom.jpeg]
Plunger bottom
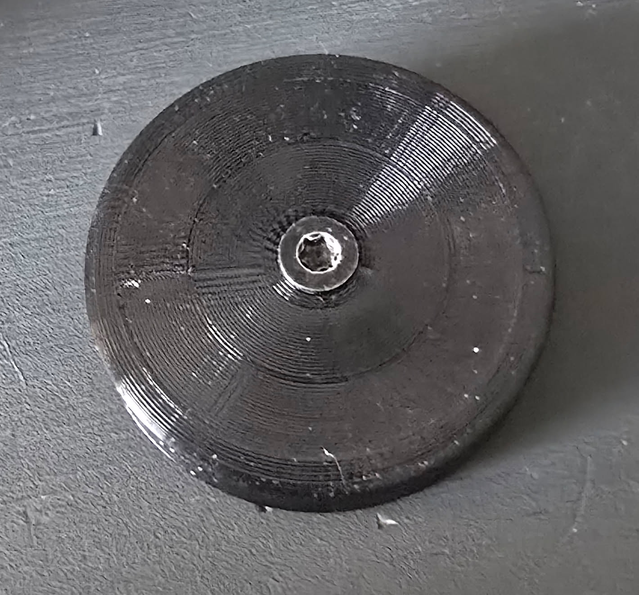
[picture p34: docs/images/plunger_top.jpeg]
Plunger top
|  |  |
|:--:|:--:|
| *Metal plate on the bottom of the plunger, screw passing through.* | *Countersunk screw seated in the top of the TPU plunger.* |

Affix the plunger to the linear rod: screw the **M4 × 14 mm** countersunk Torx screw into one **threaded end** of the linear rod.

## 3. Main body

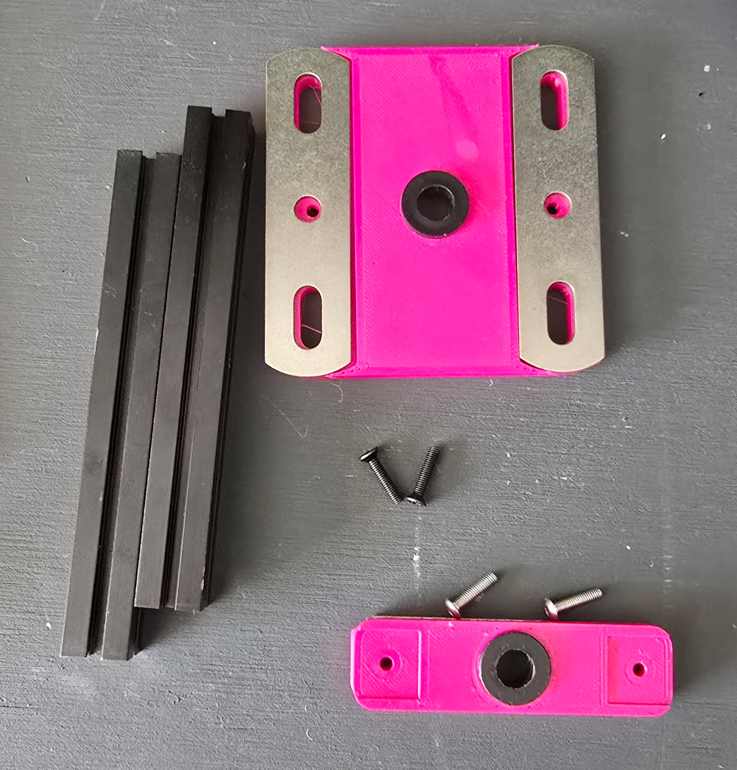
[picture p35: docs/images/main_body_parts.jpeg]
Main body parts
|  |
|:--:|
| *Parts for the main body: base, backstop, two profile extrusions, and fasteners.* |

You will need:

- Base (`base.stl`) with bushing installed
- Backstop (`backstop.stl`) with bushing installed
- **2 ×** 115 mm profile extrusions
- **2 × 80×20×2 mm** stainless steel baffles
- **6 × M3** square nuts
- **2 × M3 × 12 mm** button head screws
- **2 × M4 × 14 mm** countersunk Torx screws (through the baffles, into the extrusions)

### 3.1 Baffles

Drop the **80×20×2 mm** baffles into the recesses on the base. Pass an **M4 × 14 mm** countersunk Torx screw through the **middle hole** of each baffle; these screws will thread into the extrusions in the next step.

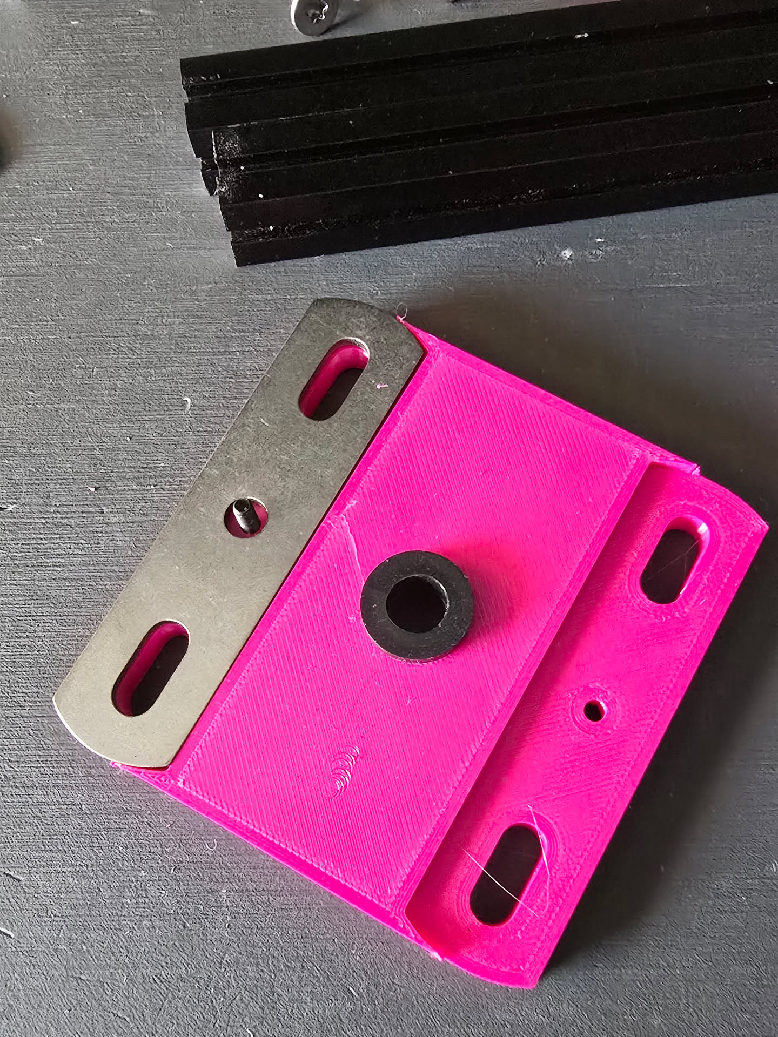
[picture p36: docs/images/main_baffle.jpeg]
Base baffles
|  |
|:--:|
| *80×20×2 mm baffle in the base, countersunk screw through the middle hole.* |

### 3.2 Extrusions

Screw the two main side extrusions onto the screws that pass through the baffles. Make sure they are **squared up**, then tighten. You can also just twist each extrusion onto the screw.

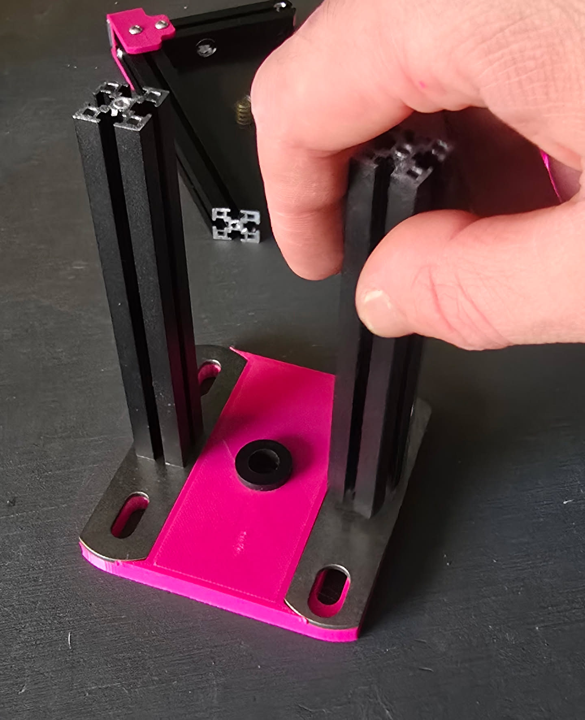
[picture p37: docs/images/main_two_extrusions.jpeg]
Main extrusions
|  |
|:--:|
| *Threading a profile extrusion onto the base.* |

### 3.3 Nuts

Slide **3 × M3 square nuts** into each extrusion: **two** in the **bottom** T-slot and **one** in the **outside** T-slot.

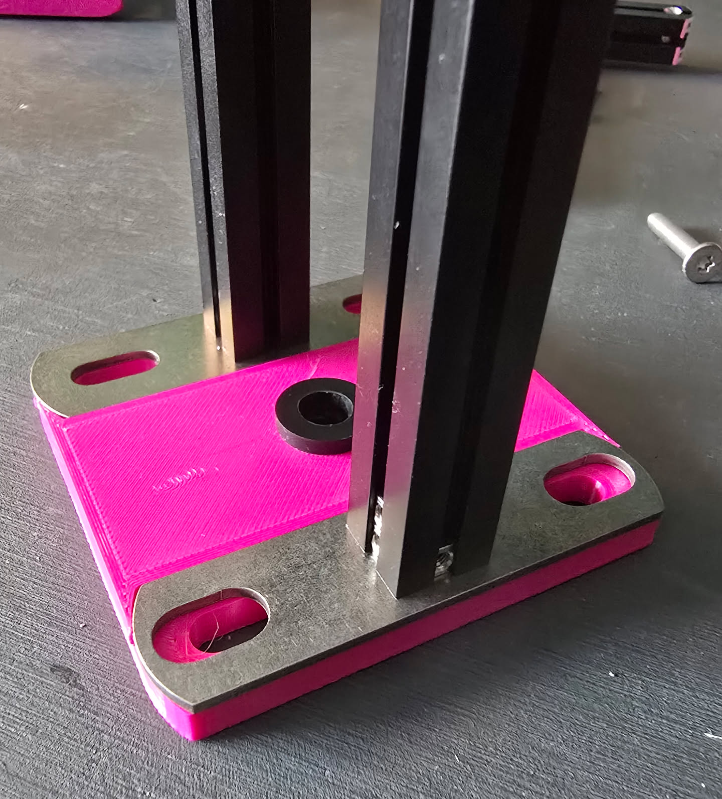
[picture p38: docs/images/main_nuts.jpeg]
Square nuts in extrusions
|  |
|:--:|
| *Square nuts slid into the bottom and outside T-slots of each extrusion.* |

### 3.4 Backstop

Screw the backstop onto the other end of each extrusion with the **2 × M3 × 12 mm** button head screws. You might need a washer so the screw holds the baffle in place.

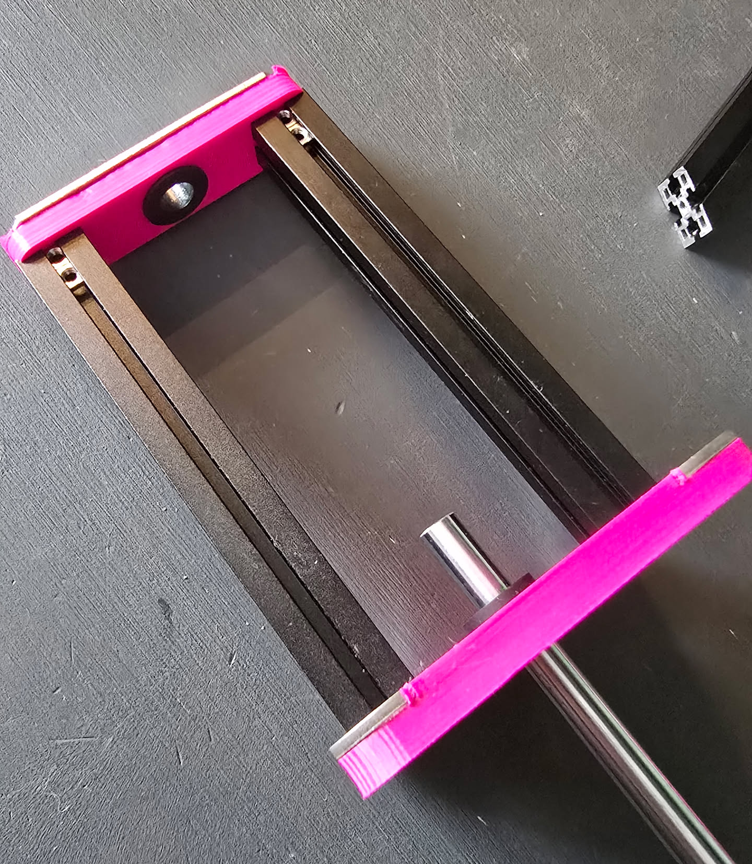
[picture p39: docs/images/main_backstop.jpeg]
Backstop attached
|  |
|:--:|
| *Backstop screwed onto the far ends of the profile extrusions.* |

## 4. Linear rod

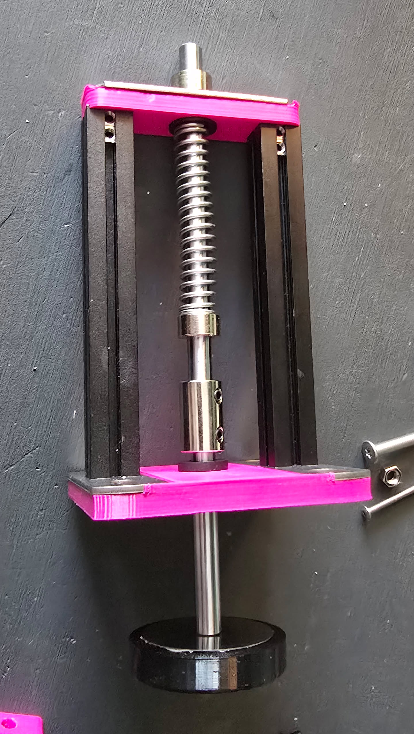
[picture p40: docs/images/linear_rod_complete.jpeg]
Completed linear rod
|  |
|:--:|
| *Completed linear rod: plunger, coupler, spring, and both shaft collars on the main body.* |

You will need:

- Plunger and linear rod from step 2
- Main body from step 3
- **8–8 mm** shaft coupler
- **2 ×** 8 mm shaft lock collars
- **70 mm** main compression spring
- **M4 × 3 mm** grub screws
- **2 ×** TPU washers (optional)

Slide the linear rod, **the end without the plunger**, into the main body through the base bushing (see the [backstop picture](#34-backstop) above).

Slide the **shaft coupler**, then a **shaft lock collar**, onto the linear rod.

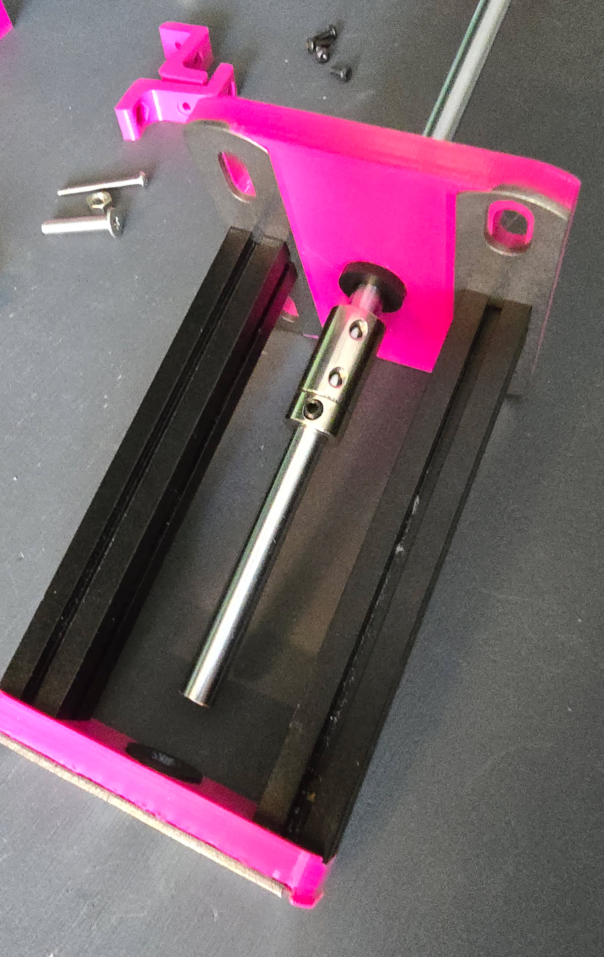
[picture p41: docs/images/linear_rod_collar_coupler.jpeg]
Coupler and collar on the rod
|  |
|:--:|
| *Shaft coupler and lock collar slid onto the linear rod.* |

Slide the **70 mm** main spring onto the linear rod, push the rod through the backstop bushing, and add the second **shaft lock collar** on the end past the backstop.

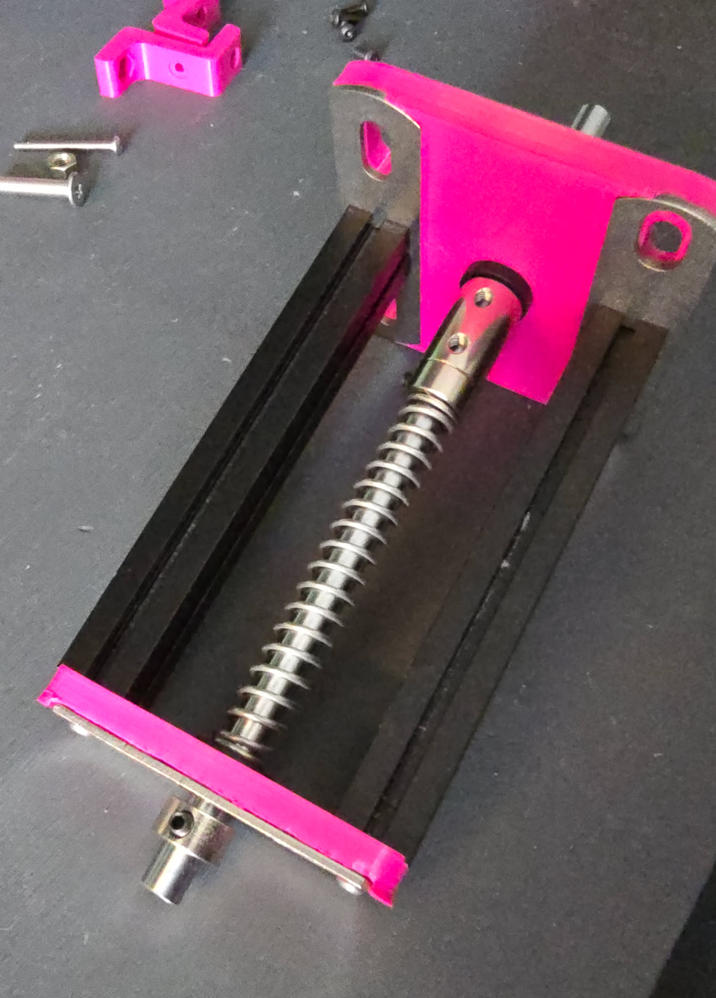
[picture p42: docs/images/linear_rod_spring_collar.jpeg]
Spring and end collar
|  |
|:--:|
| *Main spring on the rod, second shaft collar past the backstop.* |

Optionally, slide a TPU washer between the shaft collar and the main spring, and another TPU washer between the backstop and the shaft collar. This dampens vibration a bit and makes the thrusters a lot quieter.

Add the short **4 × M4 × 3 mm** grub screws to the shaft coupler. The exact position of the two shaft collars and the shaft coupler does not matter much at this point. Tighten the grub screws **lightly** so things stay in place; do not tighten them all the way yet.

You should now have a complete linear rod. Press on the plunger: the spring should push it back.

Final positions are set when you tune the thruster. See [tuning.md](tuning.md).

## 5. Hammer assembly

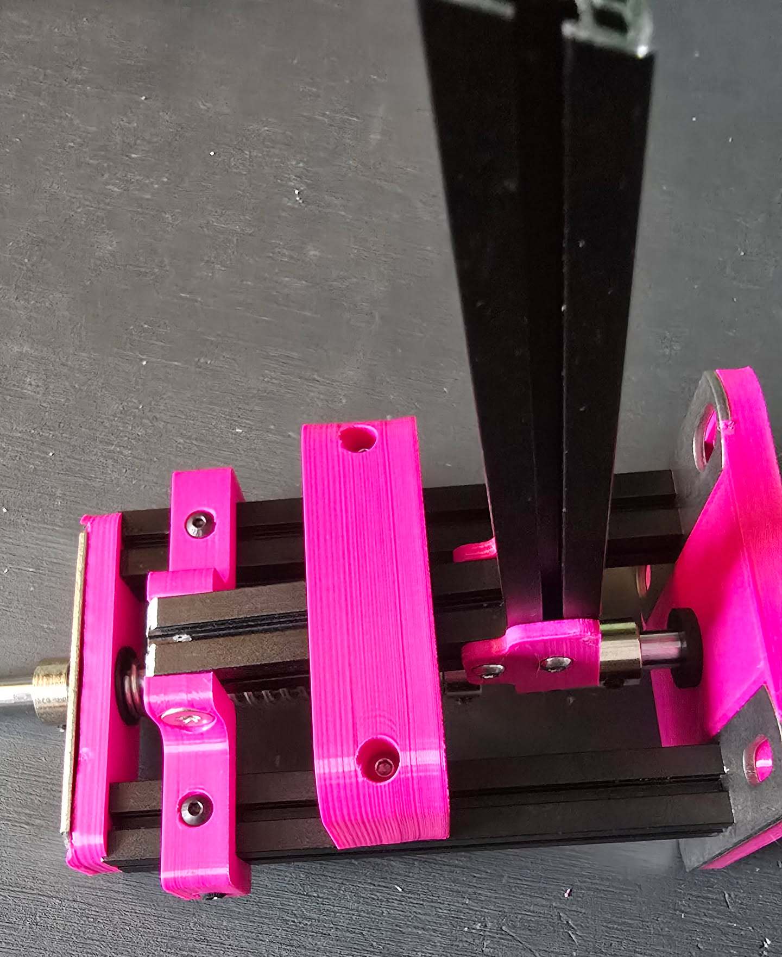
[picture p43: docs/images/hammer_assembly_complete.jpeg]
Completed hammer assembly
|  |
|:--:|
| *Completed hammer assembly: holders, pivot, spring, and spring holder on the main body.* |

You will need:

- Assembled hammer from step 1
- Main body and linear rod from steps 3–4
- Hammer holders (`hammer_holder.stl` and `hammer_holder_nut.stl`)
- Extra pair of hammer holders (optional, as a positioning guide)
- Spring holder (`spring_holder.stl`)
- **4 × M3 × 6 mm** button head screws
- **1 × M5** nut
- **1 × M5 × 25 mm** flat Torx screw
- **10 mm** hammer spring
- **2 × M3 × 30 mm** button head screws
- Threadlocker

### 5.1 Hammer holders

Line up the hammer holders about **10 mm** from the backstop. You can use an extra set of hammer holders as a guide.

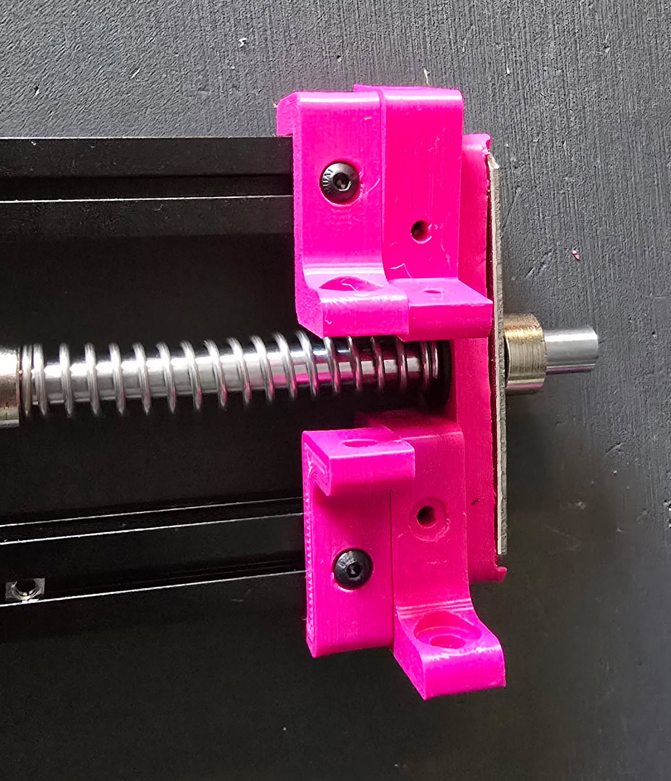
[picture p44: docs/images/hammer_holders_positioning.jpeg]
Hammer holder positioning
|  |
|:--:|
| *Hammer holders spaced ~10 mm from the backstop, using a spare pair as a guide.* |

Screw in **2 × M3 × 6 mm** button head screws in each hammer holder. They screw into the **M3 square nuts** that were previously slipped into the T-slots of the extrusions.

Slide the **M5 nut** into the nut side of the hammer holder. A **2.0 mm** socket screwdriver works well to push it in.

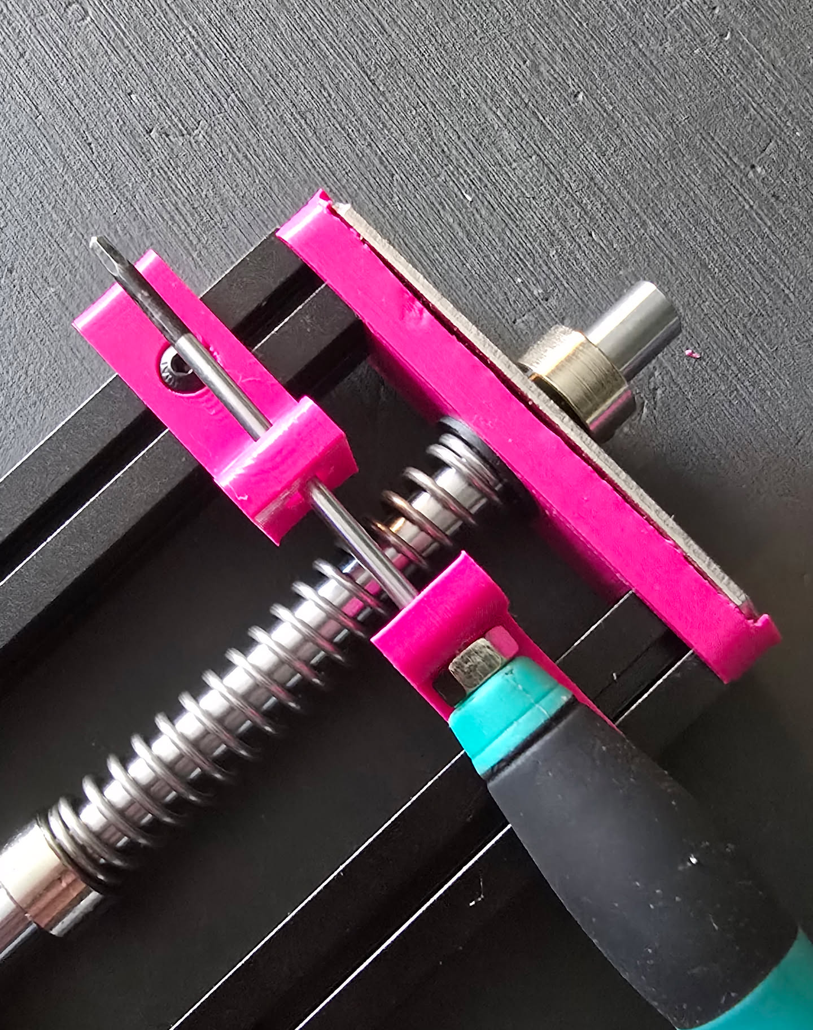
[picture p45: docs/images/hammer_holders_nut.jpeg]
M5 nut in hammer holder
|  |
|:--:|
| *Pushing the M5 nut into the nut-side hammer holder.* |

Line up the end of the assembled hammer (the end with the hole in the top extrusion) between the two hammer holders.

Slide the **M5 × 25 mm** flat Torx screw in from the screw side of the hammer holder, through the assembled hammer, and turn it just until it starts gripping the nut threads.

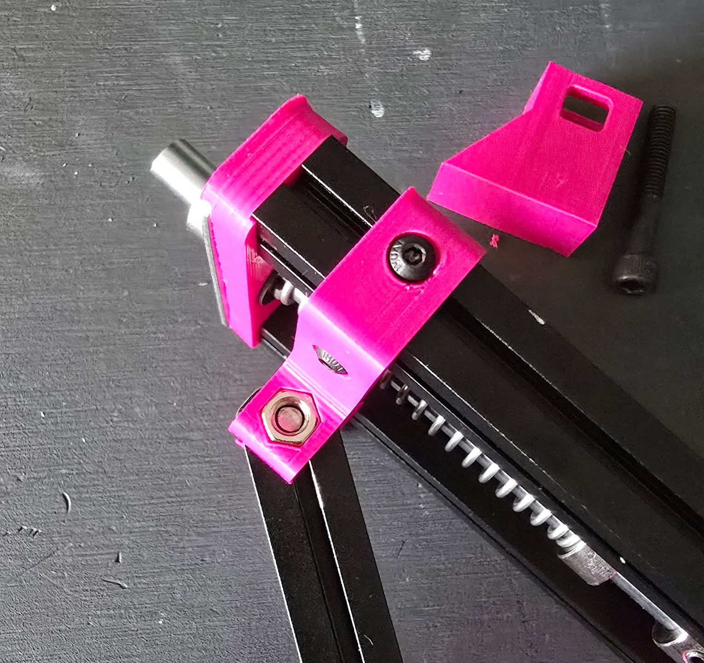
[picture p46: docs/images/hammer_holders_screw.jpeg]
M5 pivot screw
|  |
|:--:|
| *M5 pivot screw through the holders and hammer, just starting in the nut.* |

Drop a single drop of threadlocker in the nut and tighten the screw as tight as possible while still allowing the hammer to swing freely. There should be very little resistance.

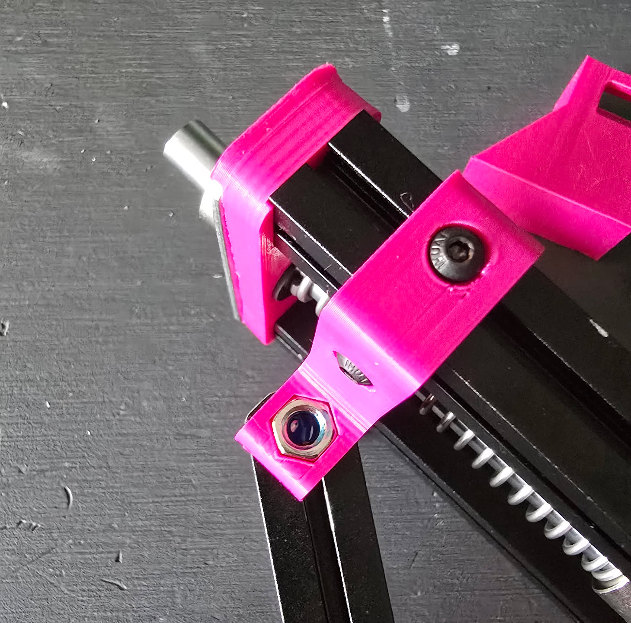
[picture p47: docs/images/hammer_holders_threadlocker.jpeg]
Threadlocker in the M5 nut
|  |
|:--:|
| *A drop of threadlocker in the M5 nut before final tightening.* |

### 5.2 Hammer spring

Drop the **10 mm** spring into the groove previously drilled in the hammer top extrusion.

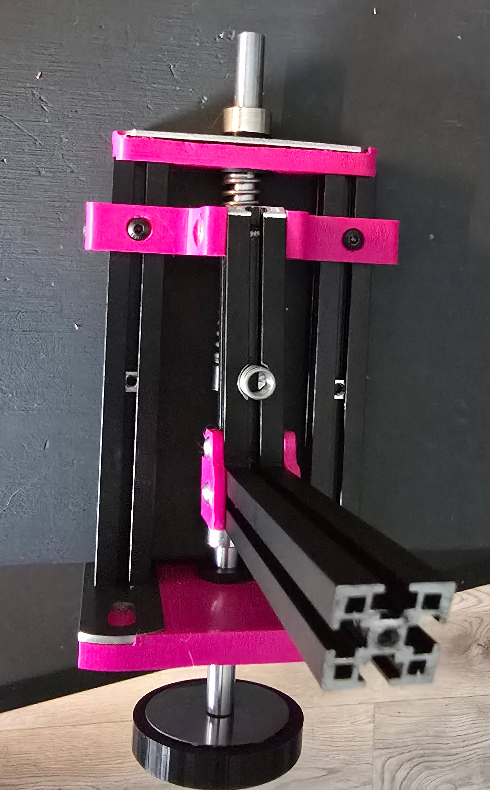
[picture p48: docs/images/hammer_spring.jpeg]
Hammer spring in the groove
|  |
|:--:|
| *10 mm hammer spring seated in the groove of the top extrusion.* |

Line up the **M3 square nuts** for the `spring_holder.stl` part.

Put the spring holder on top of the spring. Use a screwdriver to make sure the nuts line up with the part’s holes.

Drop an **M3 × 30 mm** button head screw in each hole of the spring holder and screw it into the M3 square nuts.

## 6. Pedal connector (optional)

If you chose to use the pedal connector, slip the **M6 × 40 mm** screw into the pedal connector and put a nut on top.

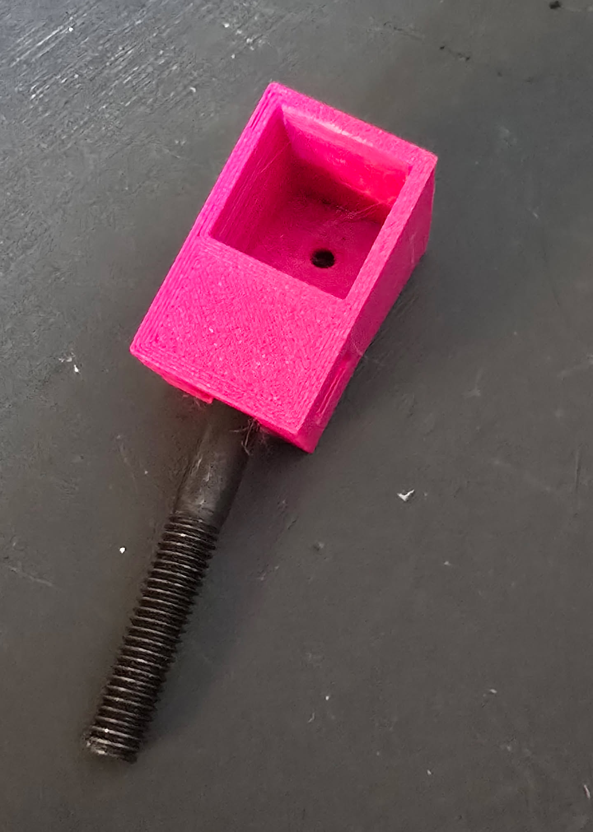
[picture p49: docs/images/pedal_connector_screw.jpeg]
Pedal connector screw
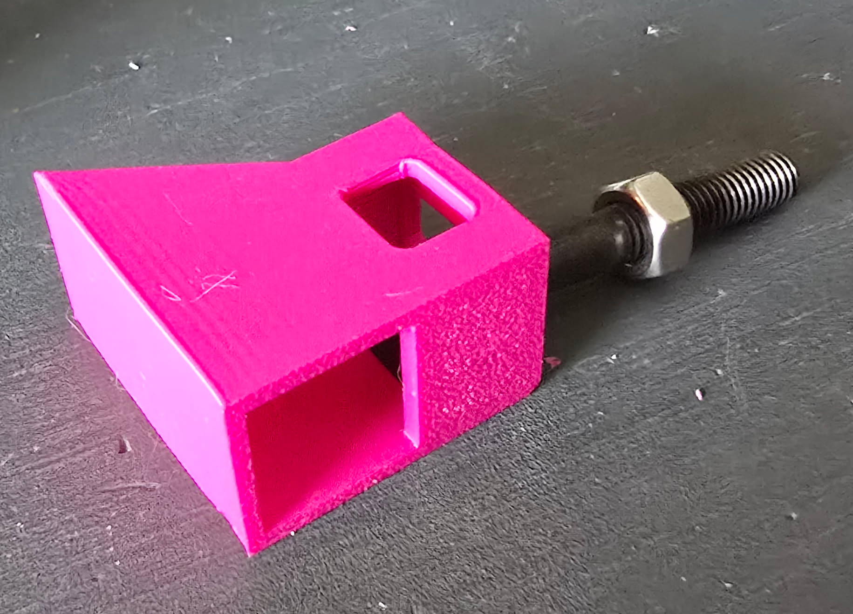
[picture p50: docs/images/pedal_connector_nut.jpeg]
Pedal connector nut
|  |  |
|:--:|:--:|
| *M6 × 40 mm screw slipped into the pedal connector.* | *Nut on the screw; use the rod coupling nut to connect to the pedal later.* |

Slide the pedal connector onto the end of the hammer and lock it in place with an **M3** screw.

Use the **rod coupling nut** to connect it to the pedal later.

## Mounting

| Assembled thruster |
|:--:|
| *Assembled thruster, ready to mount.* |

The thruster is now assembled and ready to mount.

I will not provide full instructions for the box itself. This section only covers how the thruster attaches to the face of the box.

This is **not** an actual flyball box. The board in the photos is just a placeholder to show the mounting procedure. The **M6** screws used here are also not the correct screws: they should be **countersunk** so they do not leave bumps in the matting.

You need a **2"** hole in the box face for the plunger. A hole saw is the easiest way to cut it.

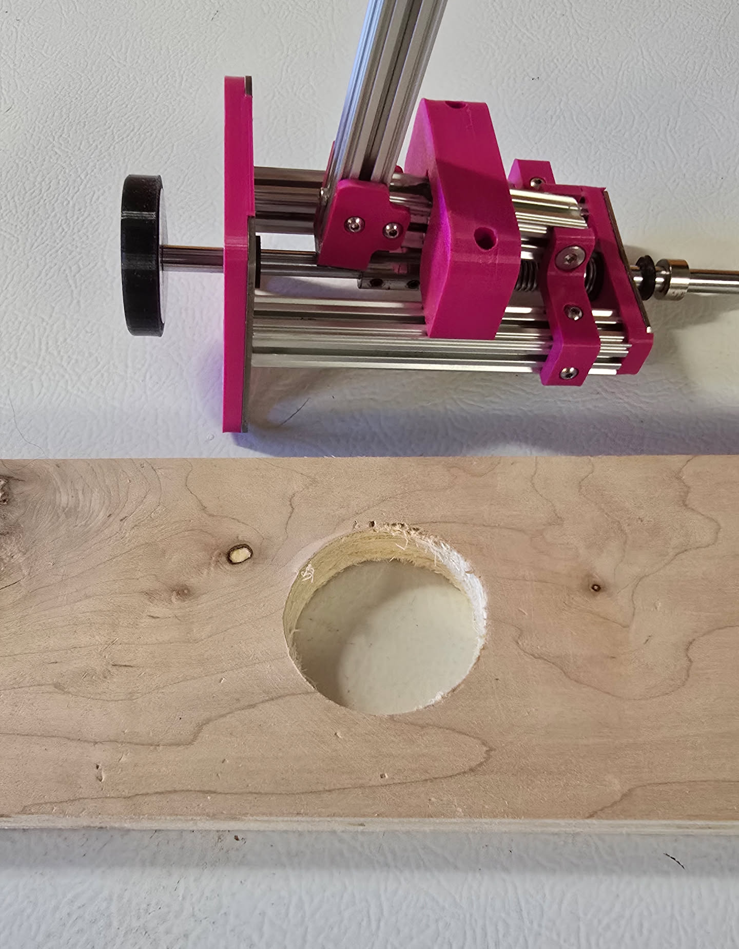
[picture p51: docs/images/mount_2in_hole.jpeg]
2" hole
|  |
|:--:|
| *2" hole cut with a hole saw.* |

Drill **4 × 6.5 mm** holes, **56 mm × 60 mm** apart, around the 2" hole. Or simply cut the 2" hole, put the thruster in place, and mark the 6.5 mm holes from the thruster.

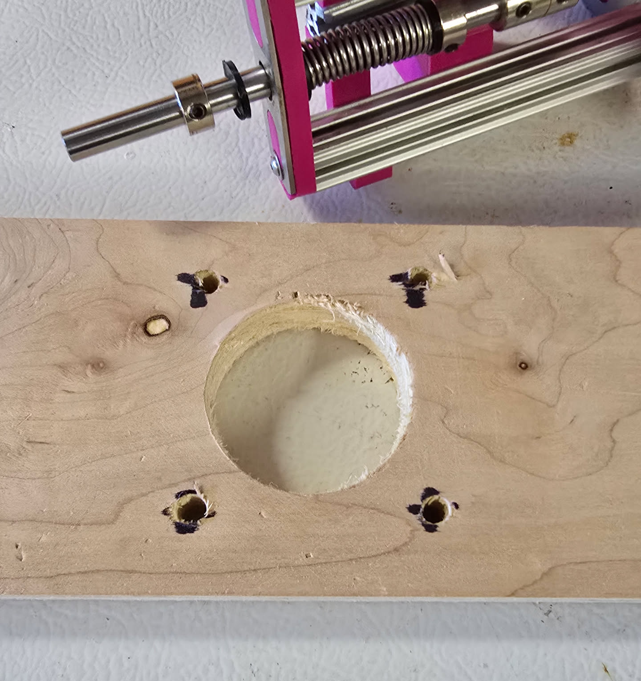
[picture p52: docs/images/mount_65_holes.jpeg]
6.5 mm mounting holes
|  |
|:--:|
| *Four 6.5 mm holes marked and drilled around the 2" hole.* |

Mount the thruster with the **4 × M6 × 60 mm** screws and the **4 × M6 nuts**. The slots in the baffles and base let you shift the thruster a bit. Line the plunger up in the middle of the hole, then tighten the nuts.

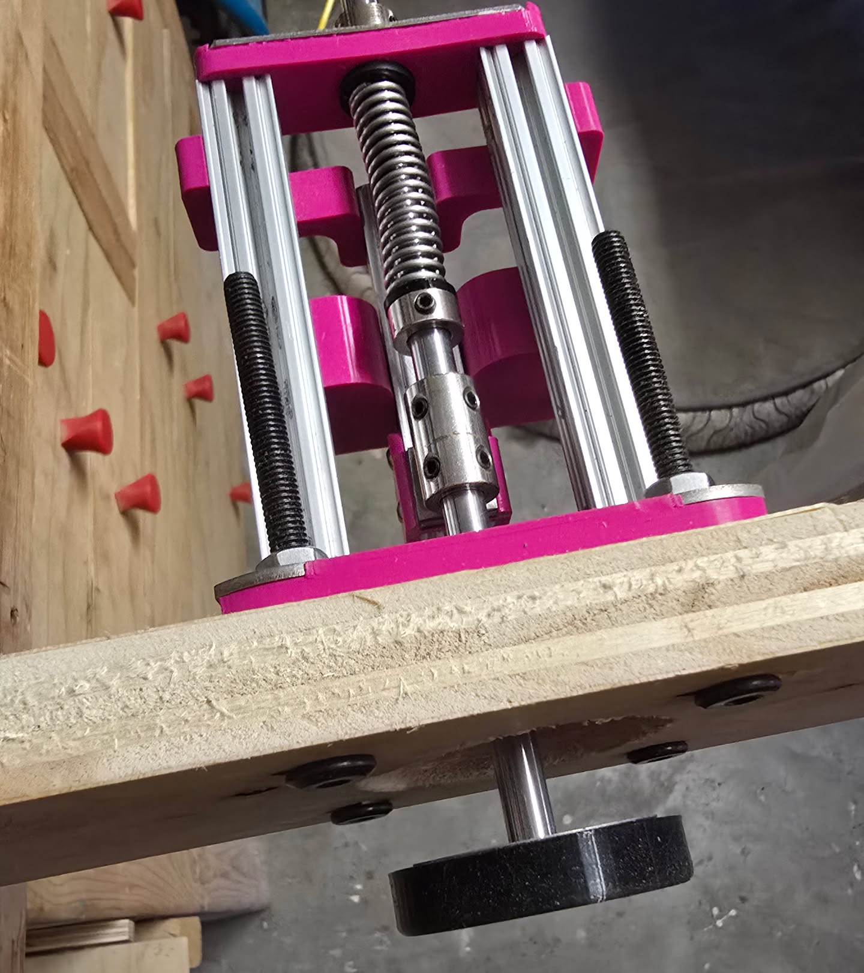
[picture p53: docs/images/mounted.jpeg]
Mounted thruster
|  |
|:--:|
| *Thruster mounted with, what should be, M6 × 60 mm screws and M6 nuts.* |

The next step is to tune the thruster. See [tuning.md](tuning.md).

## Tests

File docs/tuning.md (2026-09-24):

# Tuning

Set these in order. Adjust the **plunger position (rear collar)** before you adjust the **rest to loaded travel (shaft coupler)**.

- [Summary](#summary)
- [1. Plunger position](#1-plunger-position)
- [2. Rest to loaded travel](#2-rest-to-loaded-travel)
- [3. Ball throw distance](#3-ball-throw-distance)
  - [A note about throw distance](#a-note-about-throw-distance)

## Summary

| Adjustment | What it does | What you move |
|---|---|---|
| [Plunger position](#1-plunger-position) | Rest position of the plunger relative to the faceplate | Rear collar |
| [Rest to loaded travel](#2-rest-to-loaded-travel) | How far back the plunger goes when you load the thruster | Shaft coupler |
| [Ball throw distance](#3-ball-throw-distance) | How far the thruster throws the ball | Spring preload (collar against the spring) |

## 1. Plunger position

This sets where the plunger rests compared to the faceplate of the box. Ideally, the plunger sits **flush with your matting**.

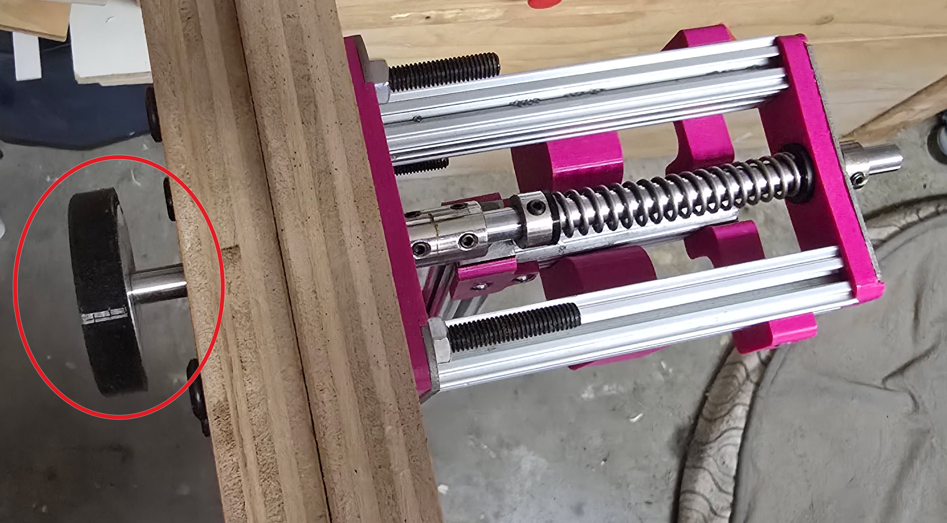
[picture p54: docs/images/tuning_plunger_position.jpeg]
Plunger rest position
|  |
|:--:|
| *Plunger at rest, lined up with imaginary 3/4" matting.* |

Loosen the grub screw on the **rear collar**. Push the plunger back as far as you want it (use a piece of wood or something similar to keep it flush with the matting) and hold it there, then tighten the collar.

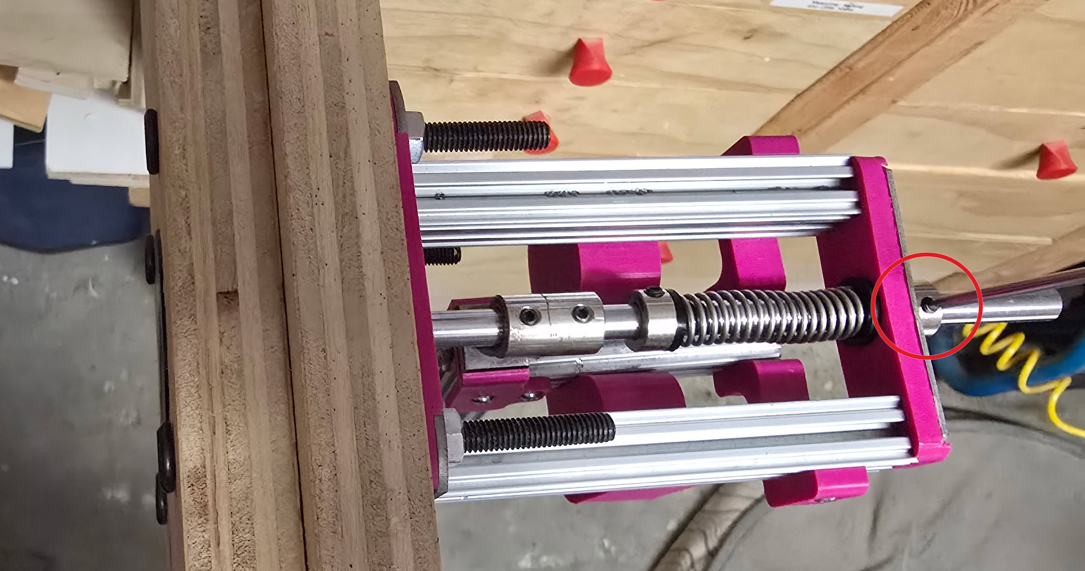
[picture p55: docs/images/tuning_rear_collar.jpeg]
Rear collar
|  |
|:--:|
| *Rear collar: loosen the grub screw, set the plunger flush, then tighten.* |

The plunger should now rest in the right spot, flush with your matting.

Changing the plunger position means you also need to adjust the rest to loaded travel.

## 2. Rest to loaded travel

Changing the position of the **shaft coupler** changes how far back the plunger goes when you load the thruster.

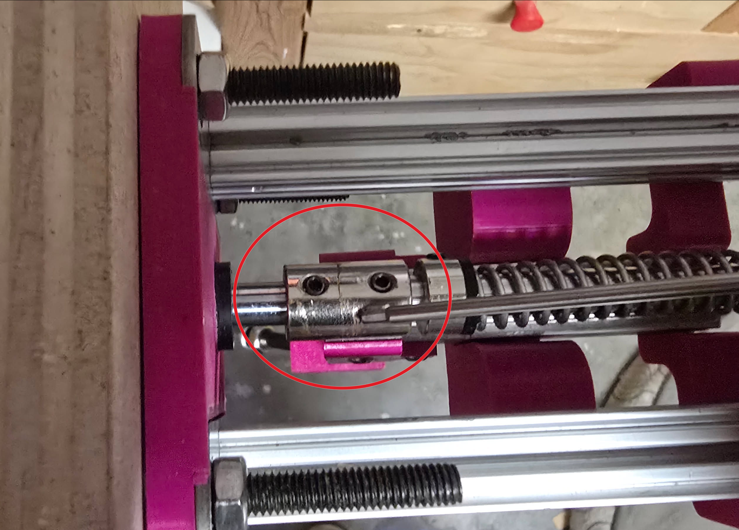
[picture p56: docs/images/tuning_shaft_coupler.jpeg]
Shaft coupler
|  |
|:--:|
| *Shaft coupler on the linear rod. Slide it to change loaded travel.* |

Sliding the shaft coupler toward the **front / base** makes the linear rod travel further when loading. It can also catch on the countersunk screw that holds the hammer head, which makes the thruster hard to load.

Sliding the shaft coupler too far toward the **spring** means the plunger does not go back far enough when you load, which can prevent balls from being loaded.

The ideal position is sitting just at the **edge of the hammer head** (the square nut at the top of the hammer). Set it there and tighten the grub screws.

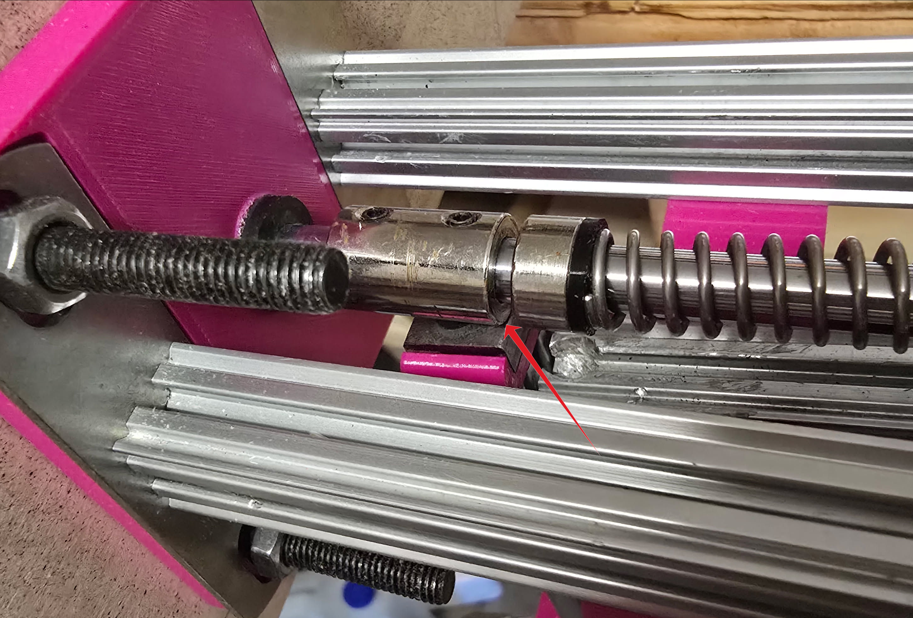
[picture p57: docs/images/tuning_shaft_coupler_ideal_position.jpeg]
Ideal shaft coupler position
|  |
|:--:|
| *Shaft coupler sitting just at the edge of the hammer head.* |

## 3. Ball throw distance

The collar sitting against the spring sets how much tension is in the main spring. That is how you tweak how hard the spring hits the ball, and how far the thruster throws it.

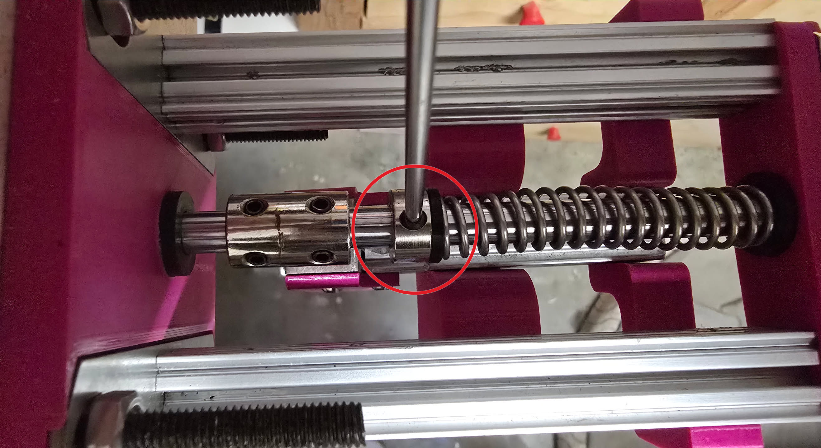
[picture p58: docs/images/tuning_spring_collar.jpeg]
Spring collar
|  |
|:--:|
| *Collar against the spring. This is the preload adjustment.* |

Move the collar closer to the **shaft coupler** for less force / preload, and a shorter throw. Move it closer to the **backstop** for more force / preload, and a longer throw.

It is typically helpful to hold the spring back if you need to move the collar toward the backstop:

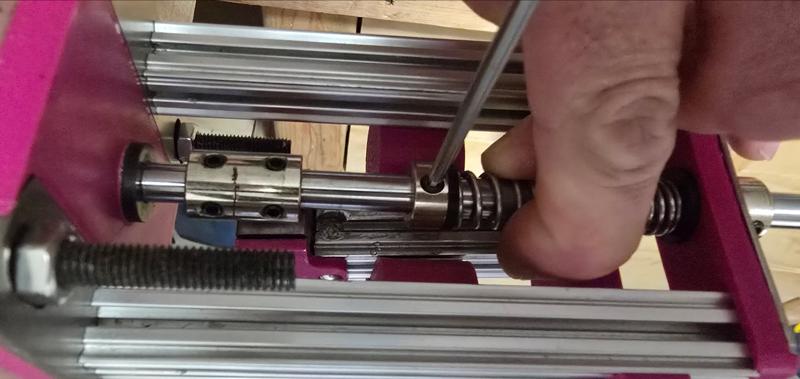
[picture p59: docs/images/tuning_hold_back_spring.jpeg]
Holding the spring back
|  |
|:--:|
| *Hold the spring back so you can slide the collar toward the backstop.* |

In my experience, this does not need to be much more than **~10 mm** further than the shaft coupler. If you need a lot of spring preload, then there might be too much friction between your linear rod and your nylon bushings.

Lock the grub screw and test it.

### A note about throw distance

**Remember that you only need the thruster to throw the ball 24" (at least in NAFA).** I tend to aim for **~26–28"**. Throwing further than that gives a very negligible increase in speed. In a perfect box turn, the dog already has its mouth around the ball as it hits the pedal.

**Making it shoot further will only cause issues with softer dogs or dogs that catches the ball in the air, far from the faceplate.**

If you want to optimize the box for faster turns, **make the pedal more sensitive** so the thruster throws the ball as soon as you touch the pedal and not when it is fully depressed.

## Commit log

2026-09-24 Initial commit; models/scad and README (instructions next)
    [backstop.scad, backstop.stl, base.scad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]
2026-09-24 Add initial instructions/assembly
2026-09-24 Update readme.md; a note about 3D printed parts
2026-09-24 Add TPU washer to assembly.md
